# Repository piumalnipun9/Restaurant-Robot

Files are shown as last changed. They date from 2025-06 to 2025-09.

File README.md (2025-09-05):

# 🤖 Evora: The Restaurant Service Robot

Evora is a modular, intelligent restaurant robot designed to enhance customer service by autonomously navigating dining areas, delivering food, interacting with guests, and providing real-time feedback. Inspired by commercial systems like BellaBot, Evora integrates mobility, interactive communication, and advanced control systems into a robust, compact design.

---

## 📦 Project Overview

Evora combines a SAM3X8E microcontroller-powered brain with reliable sensor arrays, display and audio feedback systems, and a solid mechanical frame. The subsystems are interconnected via a full-duplex RS-485 communication bus for high-speed, noise-immune data exchange.

---

## 🚀 Key Features

### 🧠 Intelligent Navigation
- **Sensors**: Equipped with **OMRON E2E inductive proximity sensors** and **A02 object avoidance modules**.
- **Capabilities**: Autonomous routing, dynamic obstacle avoidance, and safe maneuvering in busy dining environments.

### 📺 Interactive Display System
- **Display**: 7.0” TFT LCD with SSD1963 controller.
- **Function**: Displays digital menus, navigation instructions, and order confirmations.

### 🔊 Voice Feedback
- **Audio Chain**: MAX98357A DAC → Winbond W25Q128JV flash → AS041008C speaker.
- **Purpose**: Provides voice prompts and responses for improved user interaction.

### 🍽️ Tray Delivery Mechanism
- **Design**: Multi-tray system, each tray supports up to **10 kg**.
- **Engineering**: Balance and safety optimized; FEA confirms up to **265 N** load with **SF = 2**.

### 🛜 RS-232 Communication Bus
- **Architecture**: Full-duplex, multi-node capable.
- **Benefits**: Real-time communication, high noise immunity, scalable subsystem integration.

### 🔋 Power System
- **Battery**: Replaceable power unit supports **12–24 hours** operation.
- **Recharge Time**: ~4.5 hours for full cycle.

### 🛡️ Safety & Hygiene
- Emergency stop button.
- Collision detection.
- Food-safe materials and build quality.

### 🧱 Modular and Scalable
- Subsystems are modular for **easy upgrades**, **repair**, and **customization**.
- Adaptable to various restaurant layouts and service models.

---

## 🖼️ Robot Preview

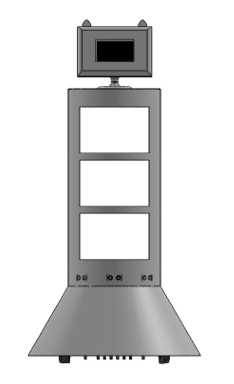
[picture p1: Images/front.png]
Front View of Evora

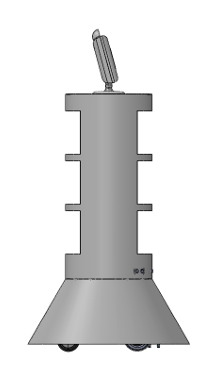
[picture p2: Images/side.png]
Side View of Evora

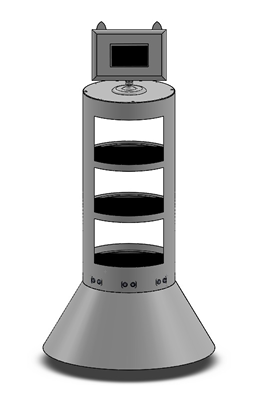
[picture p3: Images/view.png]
View1 View of Evora

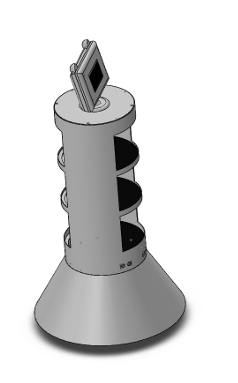
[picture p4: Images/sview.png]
View2 View of Evora


## 🖼️ Working Product
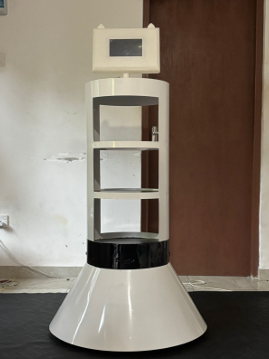
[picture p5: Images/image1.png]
  

## 🧩 PCB Design

The system is implemented on a compact 4-layer PCB to support noise-sensitive signals and high-current paths. The design emphasizes power and signal integrity while keeping the layout compact for integration into the robot chassis.

- *Top & Bottom Layers*: Signal routing  
- *Inner Layers*: Dedicated Ground and Power planes  
- *Key Considerations*:
  - Wide polygon pours for power
  - Matched-length routing for differential pairs
  - Test points for debugging and maintenance
  - Modular breakouts for sensors and displays

---

## 🖼 PCB Visuals

| Layer Stackup | 3D PCB View | 2D PCB Layout |
|---|---|---|
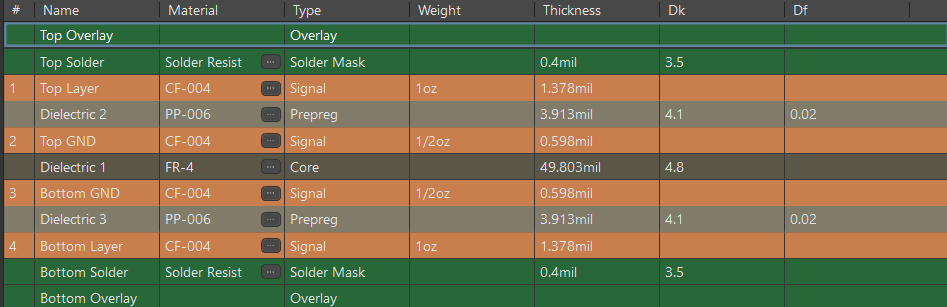
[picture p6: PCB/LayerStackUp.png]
Layer Stackup
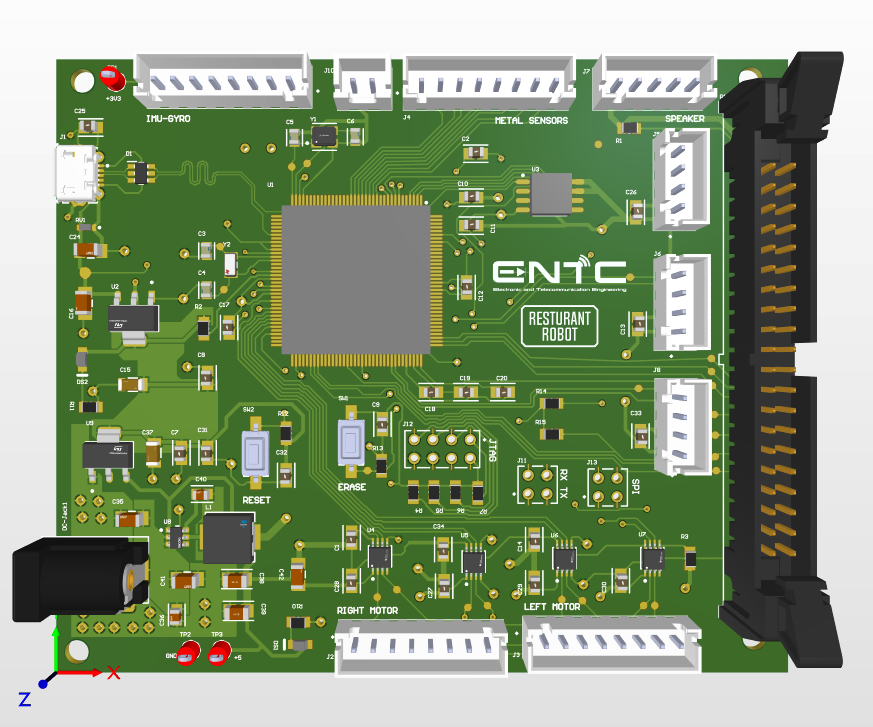
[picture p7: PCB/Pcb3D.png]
3D PCB
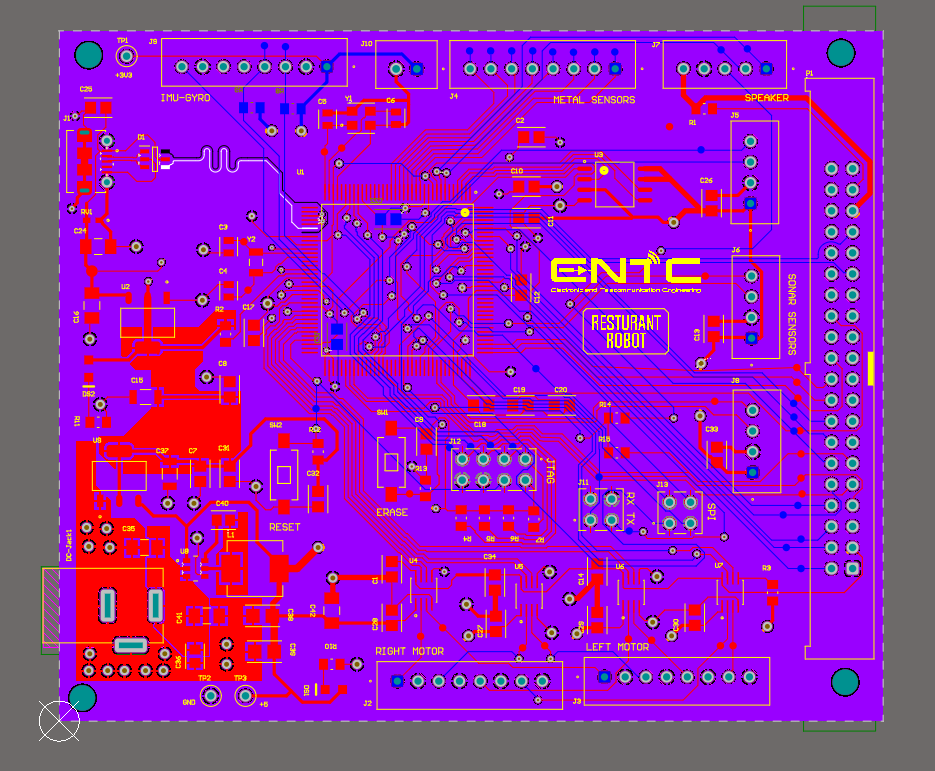
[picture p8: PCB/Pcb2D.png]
2D PCB
|  |  |  |

> 📝 The PCB height and layout were optimized to accommodate onboard regulators, high-power traces, and external motor drivers.

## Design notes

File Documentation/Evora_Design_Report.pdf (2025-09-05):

University of Moratuwa

Faculty of Engineering

Department of Electronic & Telecommunication Engineering

EN2160 - Electronic Design Realization

# Restaurant Robot

# Design Report

### Team Members:

1. Arachchi M.B.F 220040T
2. Bandara I.W.T.N 220061H
3. Boralugoda M.S 220074B
4. Karunathilake K.D.K 220310X
5. Peiris P.I.U 220452H
6. Sanjeewa P.M.G.P.N 220577U
7. Senaweera S.A.H.D 220596C
8. Viduranga J.K.A 220663F
9. Wijayarathna K.K.B.C 220705M
10. Wijenayaka M.B.T.I 220711D

July 11, 2025

Restaurant Robot | Design Report

## Contents

1 Introduction | 4
2 System Overview | 4
3 Review of Reference Product | 6
4 Block diagram | 9
5 Mechanical Design | 12
6 Hardware Design | 17

7 New Design Iteration | 32
8 Updated Mechanical Design | 32
9 Assembled Robot | 33
10 Related Calculations | 33
11 Power Supply Design | 35
12 PCB Design | 35
13 Firmware Development | 38
14 RS-232 Communication Integration | 39
15 Final Design Iteration - Overview | 40
16 Block Diagram | 40

17 Power Supply | 40
18 Display | 41
19 Enclosure Design | 42
20 PCB | 45
21 PCB Pin Allocation | 46
22 Acceleration Curve | 49
23 Firmware | 50
24 Conclusion | 50
A Appendices | 52

## 1 Introduction

### 1.1 Background of the project

Due to swift progress in service robotics and the growing need for automation in the hospitality sector, restaurant service robots have surfaced as a successful way to improve operational efficiency and increase customer experience.The worldwide shift towards contactless services, particularly during the pandemic, has expedited the incorporation of robots in customer-oriented settings.Reference models such as the BellaBot have illus-trated the viability of these robots in traversing challenging situations and executing delivery missions with considerable reliability.
Our project aims to create a restaurant robot specifically designed for indoor settings, like caf´es and dining halls. It is engineered to autonomously deliver food and engage with consumers, thereby lessening the burden on human personnel and reducing service inaccuracies.This robot provides a practical and scalable solution for the future of smart eating experiences through the integration of efficient mechanical design, robust control systems, and user-centered interaction elements.

## 2 System Overview

### 2.1 Description

Drawing inspiration from existing commercial solutions like BellaBot, this system in-tegrates mobility, interactive communication, and intelligent control within a compact, modular design.The robot is powered by the SAM3X8E microcontroller, which offers the necessary computational capabilities for controlling motors, processing sensor data, and managing display and communication tasks. The entire system is structured around multiple interconnected subsystems that communicate via a robust RS-485 full-duplex bus, allowing synchronized and reliable data exchange between modules.

### 2.2 User Need Analysis

### 2.2.1 User Needs and Expectations

1. Efficient and Accurate Food Delivery - Customers expect robots to deliver food quickly and accurately to the correct table.
2. User-Friendly Interaction - Robots should have an easy-to-use interface for customers and restaurant staff.

3. Navigation and Obstacle Avoidance - Robots must safely navigate through a crowded restaurant while avoiding obstacles.
4. Food Pickup Automation - Kitchen staff require the robot to stop at a desig-nated area to load orders.
5. Hygiene and Safety Compliance - Ensuring proper sanitization measures and food safety standards.
6. Order Status Updates - Customers may want real-time updates on their orders via displays or audio prompts.

### 2.2.2 Stake Holder Mapping

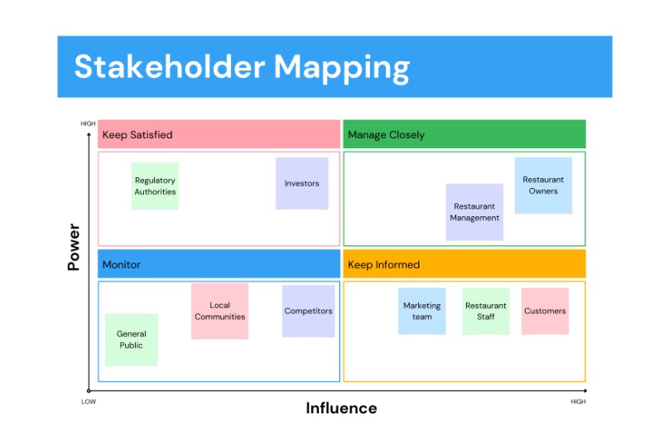
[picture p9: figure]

Figure 1: Stakeholder Map

### 2.3 Key Features in our Robot:

- Autonomous Navigation: The robot is equipped with inductive proximity sen-

sors (OMRON E2E) and object avoidance modules (A02 series), allowing it to nav-

igate safely and efficiently through dynamic environments such as crowded dining areas.

- Interactive Display System: A 7.0” TFT LCD with SSD1963 controller is used

to display menus, guide customers, and confirm orders, ensuring a user-friendly interface.

- Voice Feedback Capability: The robot uses a speaker system powered by the

MAX98357A DAC, Winbond W25Q128JV flash memory, and AS041008C speaker to provide audio feedback, improving human-robot interaction and approachability.

- Tray Delivery Mechanism: The robot supports multiple trays, each capable of

holding up to 10 kg. The mechanical design focuses on balance and safety during motion.

- Robust Communication Bus: Half-duplex RS-232 communication is used be-

tween distributed modules, ensuring real time data transmission with high noise immunity and support for multiple nodes.

- Efficient Power System: A replaceable battery provides 12–24 hours of operation

per charge, with a recharge time of approximately 4.5 hours, allowing for extended service during peak hours.

- Structural Reliability: Finite Element Analysis (FEA) using SolidWorks con-

firmed the design of the tray can handle forces up to 265 N with a safety factor of 2, ensuring mechanical robustness under load.

- Safety Features: The robot includes emergency stop functionality, collision de-

tection, and is built with hygiene compliant materials suitable for food service environments.

- Modular and Scalable Architecture: The robot’s design allows for future ex-

pansions and upgrades. Each subsystem is modular making maintenance easier and improving adaptability to different restaurant layouts or requirements.

## 3 Review of Reference Product

The design and functionality of the restaurant robot were inspired by BellaBot, a commercial service robot developed by Pudu Robotics. BellaBot is widely used in the hospitality industry for efficient and contactless food delivery.

Figure 2: Bella bot by Pudu Robotics

### Specifications

- Manufacturer: Pudu Robotics
- Height: 1290 mm
- Width: 565 mm
- Depth: 537 mm
- Weight: Approximately 55 kg
- Load Capacity: Up to 40 kg (10 kg per tray, with 4 trays)
- Battery Type: Lithium-ion
- Battery Life: 12–24 hours on a full charge

- Charging Time: Approximately 4.5 hours
- Navigation: Laser SLAM + Visual SLAM dual system
- Touch Interface: 10.1” touchscreen display
- Obstacle Avoidance: Multi-sensor fusion for 360° environmental perception
- Interactive Features: LED cat-like facial expressions, voice prompts, ambient

lighting effects

- Speed: Adjustable, up to approximately 1.2 m/s

### Key Functionalities

- Autonomous navigation with multi-point delivery
- Multi-modal interaction (touchscreen, voice, LED facial expressions)
- Automatic return to charging dock
- Obstacle avoidance in dynamic environments

Note: The BellaBot served as the reference model during conceptualisation and design requirement analysis for this project to ensure practical feature selection, ergonomic considerations, and user experience alignment. While BellaBot uses Laser SLAM and Visual SLAM for navigation, our product adopts a metal line following method, which is more suitable and cost-effective for local restaurant settings.

## 4 Block diagram

### 4.1 Conceptual Design Stage

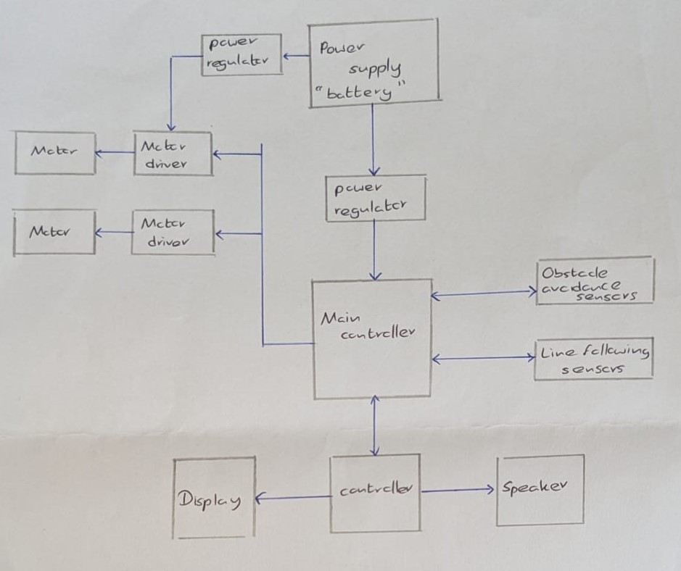
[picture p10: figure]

### 4.2 Evaluation

### 4.3 Final block diagram

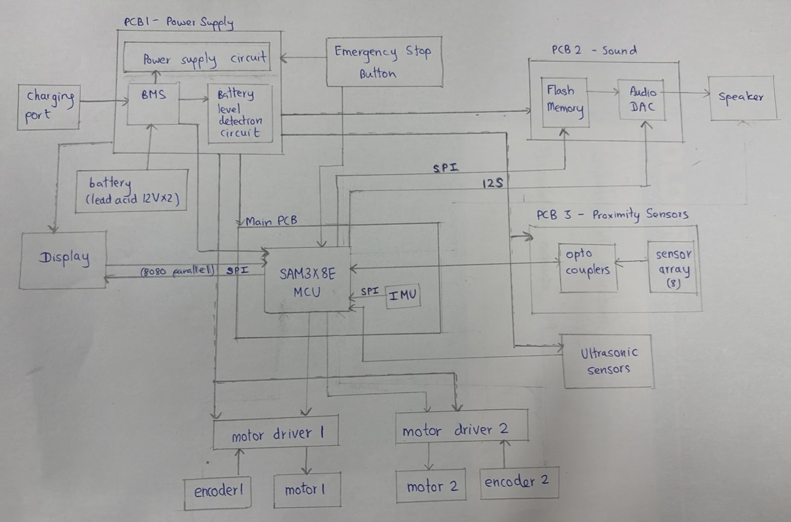
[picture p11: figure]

## 5 Mechanical Design

### 5.1 Conceptual Design Stage

### 5.1.1 Evaluation

### 5.2 Final Cross Pollinated Design

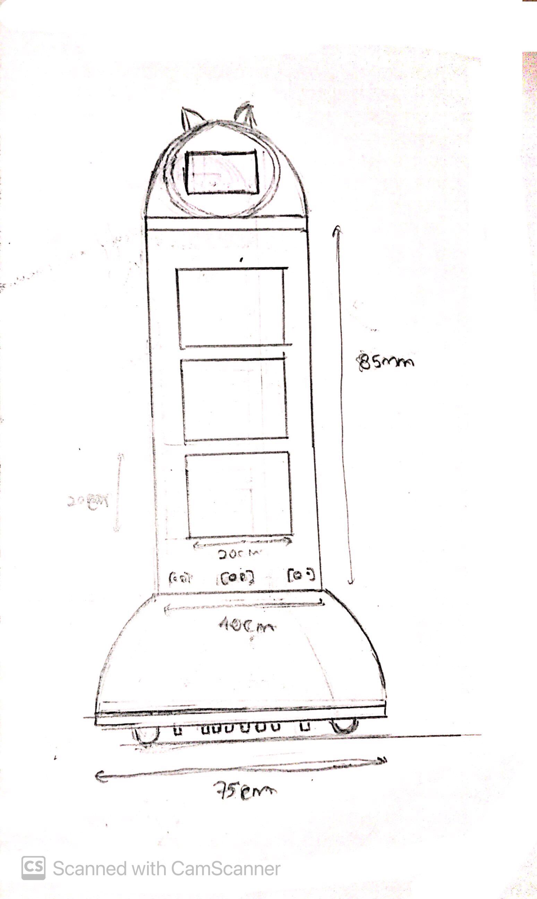
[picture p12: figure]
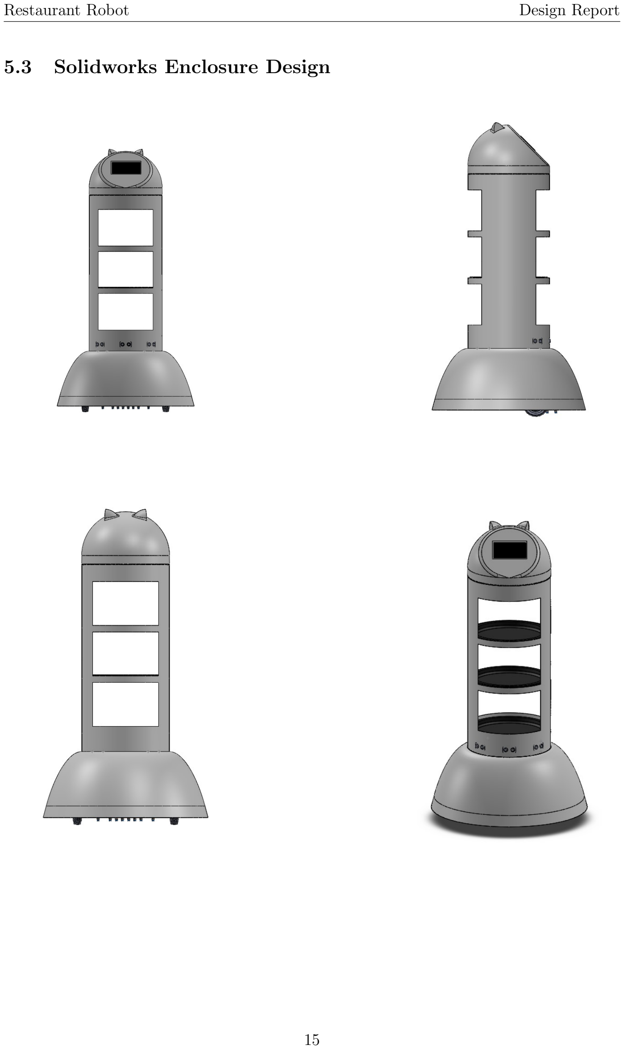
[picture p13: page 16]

### 5.3 Solidworks Enclosure Design

Figure 3: Frame designed using steel

Figure 4: Plate designed using plastic

### 5.4 Analysis

Tray Weight Analysis and Stress Simulation

## 6 Hardware Design

### 6.1 Sensors

### 6.1.1 Metal Detecting Sensors

1. OMRON welding proximity sensors( E2EW Series )
2. OMRON welding proximity sensors( E2E/E2EQ Next Series)
3. IMB Inductive proximity Sensor
4. Balluf Inductive Proximity Sensors

Table 1: Comparison
Feature | OMRON E2EW | OMRON E2E/E2EQ | SICK IMB | Balluff BES004E
Sensitivity | 3 | 3 | 2 | 3
Detection Range | 2 | 3 | 3 | 3
Response Time | 2 | 3 | 3 | 3
Robustness | 3 | 2 | 3 | 3
Harsh Environment Suitability | 3 | 2 | 3 | 3
Mounting Flexibility | 2 | 3 | 3 | 3
Interface Options | 2 | 3 | 2 | 2
Ease of Integration | 2 | 3 | 2 | 2
Availability | 3 | 3 | 2 | 3
Price Efficiency | 2 | 3 | 2 | 2
Total Points | 24 | 28 | 25 | 27

After carefully considering all the options available, we have chosen the OMRON welding proximity sensors( E2E/E2EQ Next Series) for our project.

### 6.1.2 Obstacle Detecting sensors

1. A02 series sensor module

Table 2: A02 series sensor module
Features | Advantages | Applications
3cm small blind zone | Small blind zone (5cm) | Horizontal distance sensing
3.3–5V power input | Water and dust resistivity | Car parking system
Closed waterproof bistatic probe | Strong anti-interference ability | Robot avoidance and auto-matic control

2. ME007YS Series Sensor Module

Table 3: ME007YS Sensor Module
Features | Advantages | Applications
Intelligent signal process-ing circuit, small blind zone | High-accuracy distance sens-ing | Horizontal distance sensing
Multiple interfaces: PWM, UART Auto, UART Ctrl, Switch | Stable temperature-compensated sensing | Solid level monitoring
3. A13 Series Sensor Module

Table 4: A13 Series Sensor Module
Features | Advantages | Applications
Reflective structure with narrow beam angle | High sensitivity and stable de-tection | Horizontal distance sensing
Multiple output modes: UART, PWM, RS485, Switch | Internal temperature compen-sation with anti-static design | Object classification and prox-imity sensing

Table 5: Ultrasonic Sensor Comparison
Feature | A02 Series | ME007YS Series | A13 Series
Blind Zone | 3 | 1 | 2
Measuring Range | 3 | 2 | 1
Water resistance | 3 | 2 | 0
Dust resistance | 3 | 2 | 0
Beam Angle | 3 | 3 | 1
Static Power Consumption | 3 | 2 | 2
Operating Current | 3 | 3 | 3
Temperature Range | 3 | 3 | 3
Accuracy | 3 | 3 | 3
Response Time | 3 | 2 | 2
Interface Variety | 2 | 3 | 3
Form Factor / Size | 3 | 2 | 2
Stability | 3 | 2 | 3
Anti-Static Design | 2 | 3 | 3
Temperature Compensation | 2 | 3 | 3
Total Points | 42 | 36 | 31

After carefully considering all the options available, we have chosen the A02 Series sensor for our project.

### 6.2 Actuators

### 6.2.1 Motors

1. Calculations
(a) Robot Requirements
- Total robot mass: 45 kg
- Drive system: 2 direct-drive wheels (differential configuration)
- Maximum speed: 0.5 m/s
- Acceleration: 0.2 m/s²
- Wheel diameter: 127 mm (5 in)
- Indoor use only: Low noise, non-marking tread required
(b) Motor Torque Calculation
- Force per Wheel :

F =

45 · 0.2
2

= 4.5 N

- Rolling Friction per Wheel: For rubber wheels on carpet,the rolling

resistance coefficient(Crr) is assumed to be in the range 0.03–0.05.For this

calculation,we use an estimated value of Crr=0.05.

Fr =

Crr · m · g
n

=

0.05 · 45 · 9.81
2

=

22.0725
2

= 11.036 N

- Torque Requirement :

τ = F · r = (4.5 + 11.04) · 0.0635 = 0.98679 N · m

Apply 2× safety margin:

τrequired ≈ 1.9736 N · m

- Required RPM:
Circumference = 2πr = 0.399 m | ⇒ | RPM = 0.5
| | 0.399
- 60 ≈ 75 RPM
2. Comparison

Table 6: Motor Comparison

Motor | Torque | Control | Efficiency | Cost | Integration | Feedback | Total
Pololu 37D Cytron SPG50 NEMA 23 (Open) NEMA 34 (Open) NEMA 23 Closed-Loop JMC Servo-Stepper | 15 14 22 25 24 25 | 10 10 15 15 20 19 | 10 10 9 8 13 12 | 12 14 12 10 13 10 | 14 14 13 10 14 12 | 0 0 0 0 10 10 | 61 62 71 68 94 88

After carefully considering all the options available, we have chosen the NEMA 23 Closed Loop Stepper Motor for our project.We decided to purchase YS Series 1 Axis Closed Loop Stepper CNC Kit from stepper online which includes a S Series Nema 23 Closed Loop Stepper Motor and a CL57Y Y Series Closed Loop Stepper Driver.

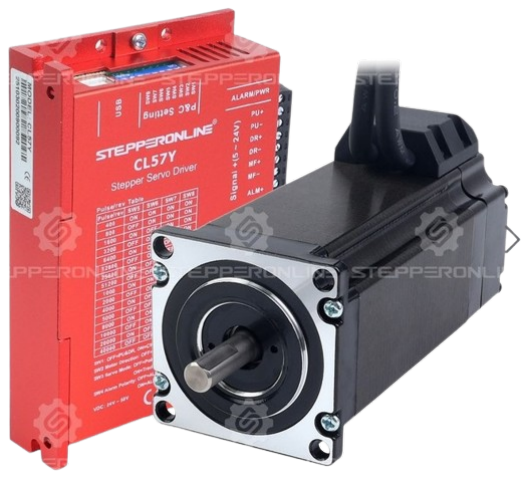
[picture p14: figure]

3. Motor Specifications
- Manufacturer Part Number: 23HS40-5004D-E1K-1M5
- Motor Type: Bipolar Stepper
- Step Angle: 1.8°

- Holding Torque: 3.00 Nm (424.83 oz.in)
- Rated Current per Phase: 5.0 A
- Phase Resistance: 0.7 Ω ± 10%
- Inductance: 2.3 mH ± 20% (1 kHz)
- Insulation Class: B (130°C / 266°F)
- Frame Size: 57 × 57 mm
- Body Length: 122 mm
- Shaft Diameter: 8 mm
- Shaft Length: 22 mm
- D-Cut Length: 15 mm
- Cable Length: 1500 mm
4. Encoder Specifications
- Output Circuit Type: Differential type
- Encoder Type: Optical Incremental
- Encoder Resolution: 1000 PPR (4000 CPR)
- Output Signal Channels: 2 channels
- Supply Voltage Range: 4 V – 5 V
- Output Current: 100 mA
- Output High Voltage: 5 V
- Output Low Voltage: 4.5 V
- Maximum Output Frequency: 60 kHz
5. Driver Specifications
- Output Peak Current: 0–7 A (0–5 A RMS)
- Input Voltage: +24–50 VDC (Typical: 36 VDC)
- Logic Signal Current: 7–16 mA (Typical: 10 mA)
- Pulse Input Frequency: 0–200 kHz
- Pulse Width: 2.5 µs
- Isolation Resistance: 500 MΩ

### 6.3 Display and UI

The restaurant robot project aims to enhance customer experience by automating tasks such as taking orders, displaying menus, and providing real-time updates. A display module is critical for this purpose, serving as the primary interface for user interaction and information sharing and we will be using a 7.0” TFT LCD Module with SSD1963 Controller for our application.

### 6.3.1 Display Specifications

Parameter | Specification
Model | 7.0” TFT LCD Module
Resolution | 800×480 pixels
LCD Type | TFT Transmissive Normal White
Interface | 16-bit parallel bus interface
PCB Color | Blue
Backlight Power Supply | On-board 400 mA DC-DC Boost regulator
Module Dimensions | 186 mm × 106 mm × 23 mm
Active Area | 154 mm × 86 mm
Pixel Pitch | 0.179 mm × 0.179 mm
Pin Header | Standard 2×20 2.54 mm pin header
Weight | 410 grams

### 6.3.2 Electrical Specifications

Parameter | Specification
Driver Chip | SSD1963
Data Port Voltage | IOVCC = VCC = 2.8V 3.3V
Operating Temperature | -20°C to +70°C
Storage Temperature | -30°C to +80°C
Touch Type | Resistive touch
Connection Method | 2.54mm pin header

### 6.3.3 Advantages

- High resolution (800×480 pixels) ensures crisp visuals.
- Resistive touch screen enables user interaction.
- Integrated backlight regulator simplifies power management.
- Pre-tested initialization code saves development time.
- Wide compatibility with the STM32 microcontroller.

### 6.4 Sound Module

The sound system in the restaurant robot is designed to provide a high-quality audio output for user interactions. The following components are selected for optimal performance.

### 6.4.1 Required Components

1. I2S to Analog Converter Options
- PCM5102A : The PCM5102A is used as the I2S DAC to convert digital

signals from the MCU into high-fidelity analog audio output. It supports up to 32-bit, 384 kHz audio and has a built-in low-noise voltage regulator for stable operation.

- MAX98357A (I2S DAC + Amplifier) The MAX98357A is an integrated

solution that combines an I2S DAC with a Class-D amplifier, providing both digital-to-analog conversion and speaker driving capabilities in a single pack-age. This space-efficient solution simplifies the audio signal chain by eliminating the need for a separate amplifier IC.Key features of this are :

– Integrated I2S audio DAC and Class-D amplifier

– 3.2W output into 4Ω speaker at 5V

– No external components required for filtering

– Low quiescent power consumption

– Filterless modulation scheme

2. Speaker Driver IC Options
- PAM8403 : The PAM8403 Class-D amplifier is a smaller, lower power option

suitable for applications where space and power consumption are critical. It provides up to 3W per channel and is easy to implement.

- LM386 : The LM386 is a classic low-voltage audio power amplifier that can

drive speakers directly. It offers adjustable gain and volume control capabilities through simple external components.Some of the key features are

– Operating voltage: 4V–12V

– Output power: 0.25W to 1W (depending on supply voltage and load)

– Adjustable gain from 20 to 200

– Low quiescent current drain

– Hardware volume control capability via external potentiometer

– Simple implementation with minimal external components

3. Flash Memory : For storing pre-recorded audio files, the W25Q256 (32MB) or W25Q128 (16MB) NOR Flash memory is used. It communicates with the MCU

via SPI and ensures fast, non-volatile storage for voice prompts and sound effects.

4. Speaker Options
- AS07108PO-LW152-WR-R (PUI Audio) :A compact yet powerful speaker is required to match the amplifier’s output. A 3W-5W, 8Ω full-range speaker

is chosen to deliver clear voice playback with a sensitivity of 86dBA.

- Visaton K 50 SQ (4ohms, 2W)

– Power handling: 2W RMS

– Impedance: 4 ohms

– Sensitivity: 84 dB (1W/1m)

– Type: Square dynamic speaker, paper cone

### 6.4.2 Design Considerations

1. Option 1: PCM5102A + PAM8403
- Highest audio quality
- Digital volume control via STM32
- Higher component count
- More PCB space required
2. Option 2: PCM5102A + LM386
- Good audio quality
- Hardware volume adjustment possible
- More analog components required
- Lower power output (0.25W–1W)
3. Option 3: MAX98357A only
- Simplest implementation
- Smallest PCB footprint
- Digital volume control only
- Good power output (3.2W at 5V)

MAX98357A provides the simplest implementation by integrating both the amplifier and digital volume control in a single chip, eliminating the need for additional analog components and reducing system complexity. Its small footprint makes it ideal for designs with tight space constraints.Despite its compact size, the MAX98357A delivers 3.2W of power output at 5V, which is sufficient for many audio applications, offering efficient amplification without the need for a separate power amplifier.

### 6.5 Microcontroller

### 6.5.1 Evaluation

After carefully considering all the options available, we have chosen the SAM3X8E microcontroller for our project.

Table 7: Microcontroller Comparison

Feature | MX RT1064 | PIC32MZ | SAME70 | SAM3X8E | Teensy 3.5/3.6 | ATSAM4S | ATSAM3S
Core | 3 | 2 | 3 | 2 | 3 | 3 | 2
I/O Pins | 3 | 3 | 2 | 2 | 3 | 2 | 1
Memory | 3 | 3 | 2 | 1 | 3 | 2 | 2
Speed | 3 | 3 | 2 | 1 | 3 | 2 | 2
USB Support | 3 | 3 | 2 | 2 | 3 | 2 | 2
Communication | 3 | 3 | 3 | 2 | 3 | 3 | 2
Motor Control | 3 | 2 | 2 | 2 | 3 | 3 | 2
DMA Support | 3 | 2 | 3 | 0 | 2 | 2 | 2
Power Efficiency | 2 | 2 | 2 | 3 | 2 | 3 | 3
Touch Interface | 3 | 3 | 3 | 2 | 2 | 2 | 1
Parallel Interface | 3 | 2 | 2 | 3 | 1 | 2 | 1
Development Tools | 3 | 2 | 2 | 3 | 3 | 3 | 2
Community Support | 1 | 2 | 3 | 2 | 3 | 2 | 2
Cost Efficiency | 0 | 1 | 1 | 3 | 0 | 2 | 3
Ease of Programming and Debugging | 2 | 2 | 2 | 2 | 3 | 2 | 2
Low Power Modes | 2 | 1 | 2 | 2 | 2 | 3 | 3
Total Points | 41 | 38 | 41 | 42 | 40 | 42 | 39

### 6.5.2 Details of SAM3X8E

1. Core and Speed : We chose the SAM3X8E because it features an ARM Cortex-M3 core running at 84 MHz. Although there are faster options available, this clock speed provides the perfect balance between performance and power consumption for our requirements. The SAM3X8E is powerful enough to handle tasks like driving the SSD1963 LCD, managing motor control, and processing sensor data, without being overkill for our project.
2. I/O Pins : We need a microcontroller with sufficient digital and analog I/O pins

to handle the requirements of the display,motor controller, sensor inputs, and sound module. The SAM3X8E offers 54 digital I/O pins and 12 analog pins, which is more

than enough to support

- SSD1963 : The parallel interface (16-bit) is fully supported with available

digital pins

- Motor Control: We can easily control multiple motors using PWM signals.
- Sensor Inputs: The 12 analog pins give us ample capacity to handle sensor

data.

- Sound Module: We have enough I/O pins to interface with the sound mod-

ule.

3. Communication Interfaces : For communication, we need a microcontroller that supports protocols like SPI, I2C, and UART. The SAM3X8E supports all these protocols, which gives us the flexibility to interface with the SSD1963 LCD, motor controllers,sensors, and sound modules. The microcontroller’s ability to handle these interfaces makes it ideal for our design.
4. Development Tools : We also considered the availability of development tools, and the SAM3X8E comes with support for Atmel Studio, which is a free and powerful tool for development. It’s a great advantage to be able to use a professional IDE without any additional costs.
5. Parallel Interface (16-bit/8-bit) : A key feature for us was the support for a

16-bit parallel interface. This is critical for driving the SSD1963 display, as parallel communication allows for faster data transfer compared to serial interfaces. The SAM3X8E provides this interface, ensuring that we can update the display quickly and efficiently.

6. Cost : We also found that the SAM3X8E is reasonably priced compared to other microcontrollers with similar features. It offers a good balance between performance and cost, making it an affordable option for our project.

### 6.5.3 Power Requirements Analysis

The table below shows the power consumption of all robot components:

Component | Quantity Voltage (V) Current (A) Power (W)
Nema 23 motors | 2 | 24 | 4.2 | 201.6
AO2 PWM Ultrasonic sensors | 3 | 5 | 0.04 | 0.6
Proximity sensors | 8 | 12 | 0.003 | 0.288
7-inch TFT LCD Display | 1 | 5 | 0.12 | 0.6
SAM3X8E MCU | 1 | 3.3 | 0.8 | 2.64
Motor drivers CL57T (logic) | 2 | 24 | 0.016 | 0.768
Display backlight (21 LED) | 1 | 12 | 0.14 | 1.68
Total Power Consumption | | | | ≈ 210

### 6.5.4 Battery Capacity Calculation

Short-Duration Operation (2 hours)

- Energy requirement: 210 W × 2 h = 420 Wh
- Capacity at 24V: 420 Wh
24 V = 17.5 Ah
- Recommended capacity (with 20% safety margin): 17.5 Ah × 1.2 = 21 Ah

Extended Operation (4 hours)

- Energy requirement: 210 W × 4 h = 840 Wh
- Capacity at 24V: 840 Wh
24 V = 35 Ah
- Recommended capacity (with 20% safety margin): 35 Ah × 1.2 = 42 Ah

For testing purposes and considering affordability, we will use 9Ah batteries in the current prototype.

### 6.6 Wheels

### 6.6.1 Wheel Options

1. BaneBots Wheel
2. Tebru Industrial Robot Wheel
3. AGV Drive Wheel
4. Modified Heavy Duty Wheel - Robokits India

### 6.6.2 Shaft Hub Options

1. Pololu 8mm Hub

In conclusion, finding the right wheel for our 8 mm shaft setup has proven challenging due to either compatibility issues or high costs. The best solution appears to be going for a less costly wheel, because of that we chose the Modified Heavy Duty Wheel from Robokits India.

### 6.7 Flow Chart

### 6.7.1 Conceptual Design

### 6.7.2 Evaluation

### 6.7.3 Final Cross-Pollinated flow chart

## 7 New Design Iteration

This section outlines the key improvements and additions made in the latest iteration of the design. Each update was implemented based on evolving project requirements.

## 8 Updated Mechanical Design

In the latest iteration, the SolidWorks enclosure design was revised to improve manufac-turability and cost effectiveness.

### 8.1 Updated SolidWorks Design

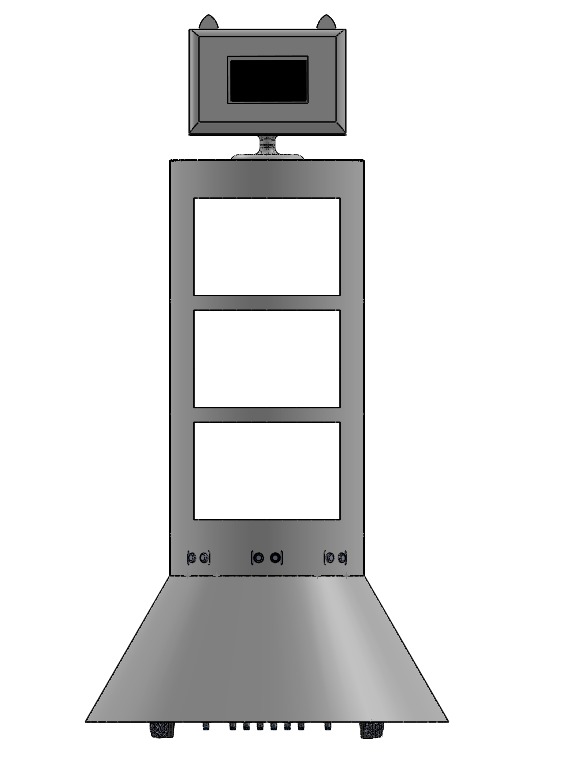
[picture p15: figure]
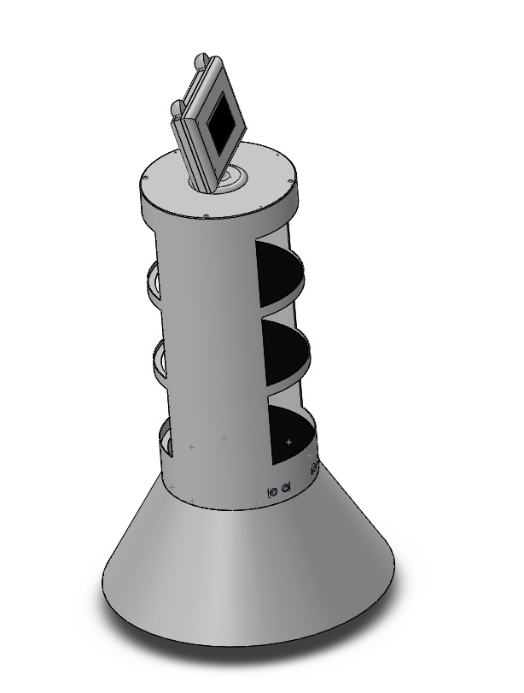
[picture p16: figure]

## 9 Assembled Robot

Figure 5: Robot After Assembly

## 10 Related Calculations

### 10.1 Mathematical Equation for Acceleration S-Curve

The acceleration velocity profile of the robot is modeled using a sigmoid function. This approach enables smooth transitions from rest to the maximum velocity Vmax, avoiding abrupt acceleration spikes that could affect mechanical stability or user comfort. The velocity function v(t) over time is defined as:

v(t) = Vmax 1 + e −K(t−X0)

Where:

- v(t) — velocity at time t
- Vmax — maximum velocity (e.g., 50.0)
- K — steepness factor that controls how fast acceleration ramps up (positive con-

stant)

- X0 — midpoint of the sigmoid curve (i.e., the time when velocity reaches Vmax
2

)

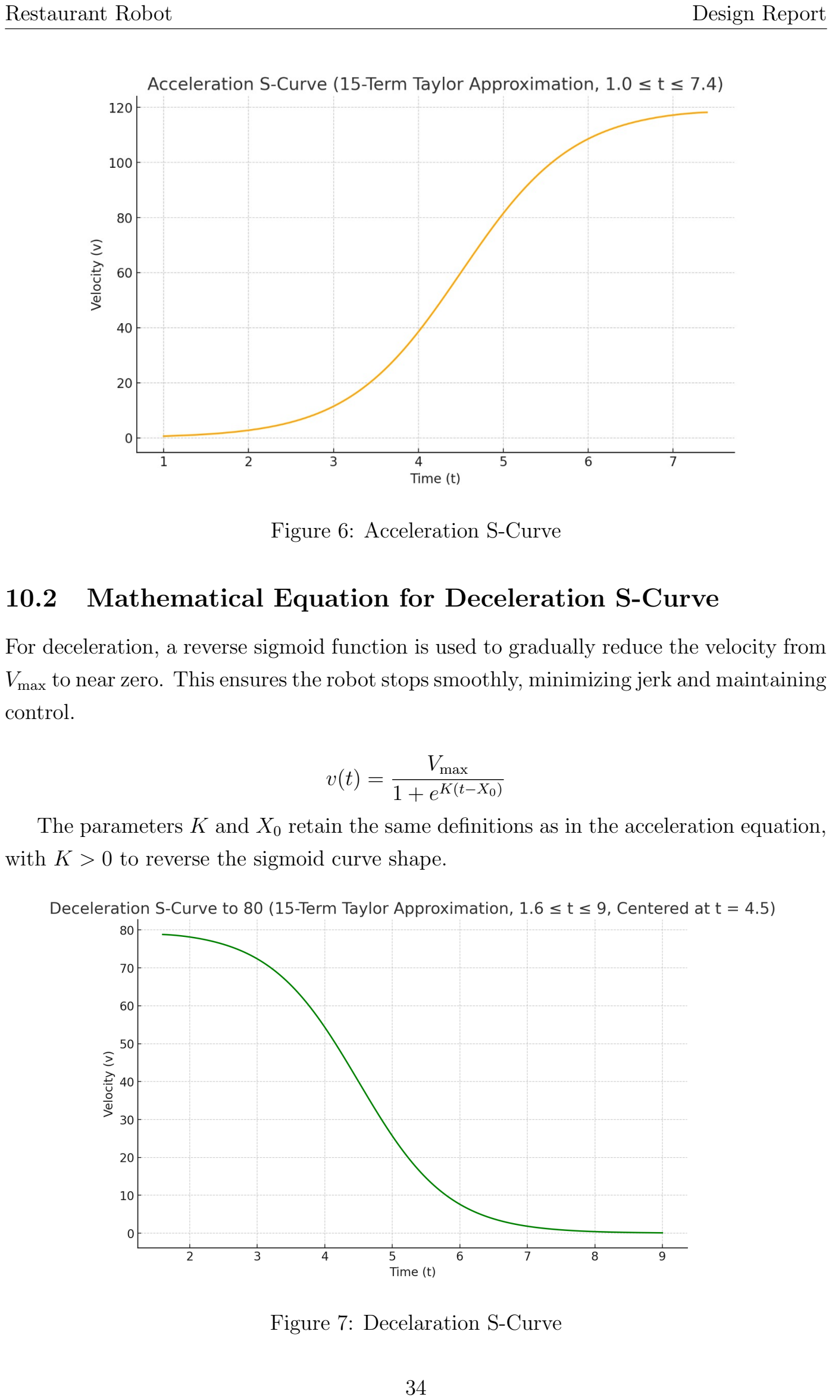
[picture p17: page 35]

Figure 6: Acceleration S-Curve

### 10.2 Mathematical Equation for Deceleration S-Curve

For deceleration, a reverse sigmoid function is used to gradually reduce the velocity from Vmax to near zero. This ensures the robot stops smoothly, minimizing jerk and maintaining control.

v(t) = Vmax 1 + eK(t−X0)

The parameters K and X0 retain the same definitions as in the acceleration equation, with K > 0 to reverse the sigmoid curve shape.

Figure 7: Decelaration S-Curve

### 10.3 Use in Motion Planning

These equations were used to program smooth acceleration and deceleration phases in the robot’s motor control logic. By adjusting the parameters K and X0, the team could fine-tune how quickly or gradually the robot transitions between different speeds, enabling efficient, safe, and comfortable movement across the restaurant floor.

## 11 Power Supply Design

The power supply system was designed to provide stable and efficient voltage levels required by various subsystems of the project. A rechargable LiPo battery pack was selected as the primary power source due to its high energy density, lightweight nature, and ability to deliver high discharge currents suitable for motor drivers and processing units.

### 11.1 Power Regulation Architecture

The output from the LiPo battery is first boosted to 24V using a high-efficiency DC-DC boost converter. This 24V rail serves as the main power bus for high-power components such as motor drivers. Subsequently, the 24V line is stepped down to 12V using a buck converter to power intermediate subsystems.
Within the main PCB, the 12V supply is further regulated to 5V and 3.3V using linear and switching regulators to supply logic-level components, sensors, and microcontrollers. This tiered voltage regulation strategy ensures optimal power distribution, minimizes power losses, and isolates noise-sensitive components from high-current lines.

## 12 PCB Design

### 12.1 Main PCB Design

A 4-layer PCB was designed to meet the signal integrity, power distribution, and compact layout requirements of the system. This multi-layer structure allows for better separation of power and signal planes, reduced electromagnetic interference, and efficient routing.

### 12.2 Layer Stackup

The printed circuit board (PCB) for the robot was designed as a 4-layer stack to ensure signal integrity, reduce electromagnetic interference (EMI), and support high-current

power delivery. The layer configuration is as follows:

Table 8: PCB Layer Stackup
Layer | Description
Top Layer | Signal routing
Layer 2 | Ground plane
Layer 3 | Power plane and additional ground zones
Bottom Layer | Signal routing

Figure 8: Layer-wise PCB Views

### 12.3 Key Considerations

The following key considerations were taken into account during the PCB design and fabrication process:

- Wide Power Traces and Polygon Pours: Power traces were made wider and

polygon pours were applied to high-current paths to minimize voltage drop and thermal resistance, thereby improving overall power integrity and heat dissipation.

- Strategic Component Placement: Components were placed to ensure optimal

signal flow, minimize trace lengths, and reduce noise. Special attention was given to the placement of sensitive analog and high-frequency components.

- Voltage Regulator Placement: The voltage regulator was positioned in accor-

dance with the layout guidelines provided in its datasheet, ensuring proper thermal management and reliable voltage regulation.

- Differential Pair Routing: Differential signal lines were routed using matched-

length traces with controlled impedance. This reduces electromagnetic interference (EMI) and ensures signal integrity for high-speed communication.

- Test Point Provisioning: Dedicated test points were added at critical locations

across the board to facilitate debugging, signal probing, and quality control testing. This enhances the maintainability and testability of the final product.

### 12.4 PCB

Figure 9: Final PCB Renderings

### 12.5 Sensor Array PCB Design

In addition to the main control board, a separate PCB was designed specifically for the ultrasonic sensors. This modular approach allows for easier maintenance, signal isolation, and optimized sensor placement within the mechanical enclosure.

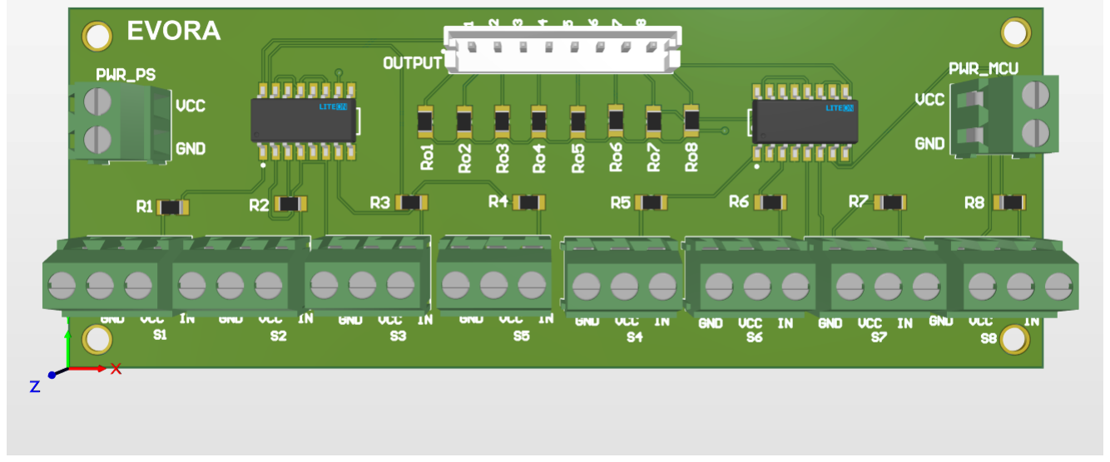
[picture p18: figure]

Figure 10: PCB for the Proximity Sensor array

## 13 Firmware Development

The firmware for the restaurant robot was developed in C using the Atmel Software Framework (ASF) and deployed on the SAM3X8E microcontroller. It manages key func-

tionalities such as line following, obstacle detection, motor control, display updates, and inter-module communication.

### 13.1 Modular Architecture

The firmware is divided into several functional modules, each responsible for a critical subsystem. These include:

- Motor Control: PWM signals are generated to drive two NEMA 23 closed-loop

stepper motors. Acceleration and deceleration are managed using S-curve velocity profiles for smooth motion.

- Sensor Handling: Data from proximity and ultrasonic sensors are continuously

read and processed to detect obstacles and junctions for decision-making during navigation.

- Line Following Algorithm: A PID control algorithm calculates error based on

sensor input and adjusts the motor speeds to follow metal paths embedded under the floor.

- S-Curve Velocity Profiling: Acceleration and deceleration curves are imple-

mented using sigmoid functions to ensure smooth speed transitions and mechanical stability.

- Display Interface: The 7” TFT LCD is controlled via a parallel interface to

display order status and user interaction elements. Display logic is separated from core navigation code for modularity.

- Obstacle Response: In case of detected obstacles, the robot executes a controlled

deceleration sequence and makes path decisions based on junction detection logic.

## 14 RS-232 Communication Integration

RS232 communication was integrated into the system to enable reliable serial communication between microcontrollers (MCUs), particularly for cases where asynchronous,

long-distance, or noise-tolerant data transmission is required. The MAX3232 transceiver module was used to convert TTL-level UART signals from the microcontroller to RS232-compliant voltage levels, allowing seamless interfacing with devices that operate on RS232 standards.
This module was chosen for its dual-channel support, low power consumption, and compatibility with a wide operating voltage range, making it ideal for embedded applications. A suitable DB9-compatible connector was included on the PCB for secure and standardized physical interfacing.
By incorporating RS232 communication, the design supports inter-MCU coordination, modular subsystem development, and future expandability with external debugging tools or legacy RS232-based controllers.

## 15 Final Design Iteration - Overview

This section presents the updates and changes implemented in the final design iteration of the restaurant robot. Throughout this stage, the team focused on refining critical subsystems to enhance the robot’s functionality and integration for deployment-ready performance. This final design iteration includes the replacement of the display module, redesign of the robot head, finalization of the power supply, and integration of custom PCBs into the robot to replace earlier development boards.

## 16 Block Diagram

This section presents the final block diagram of the restaurant robot, reflecting all system updates and integrations made in the final design iteration.

Figure 11: Final Block Diagram

## 17 Power Supply

In the final iteration, an updated power supply architecture was implemented to ensure stable operation of all subsystems. An 11.1V LiPo battery is used as the main power source. This voltage is boosted to 24V using a dedicated boost converter module, which supplies power to the two motor drivers and the ultrasonic sensor array. Additionally, the 11.1V battery voltage is bucked down to 9V using a buck converter module, and this 9V supply is provided to the main PCB. Within the PCB, onboard regulators are used to further regulate the voltage to 3.3V and 5V as required by the microcontroller, display module, and other electronic components.

Figure 12: Final Power Supply Block Diagram

## 18 Display

In the final design iteration, the initial 7-inch TFT LCD display was damaged due to an unexpected electrical issue that caused it to burn out. As a result, the team had to move on to a smaller display module due to budget constraints. The replacement display used was a TFT LCD Shield 2.4” Socket Touch Panel Module. Although smaller in size, this display provided adequate functionality for the robot’s interface requirements.
The touch display allows users to choose the table to be served and to turn on or off the googly eyes of the robot. Initially, the googly eyes were planned to be integrated graphically within the 7-inch display interface. However, due to the change in display size and resolution, the team implemented the googly eyes using two 8×8 LED matrices,

which effectively emulate two animated eyes on the robot’s head.

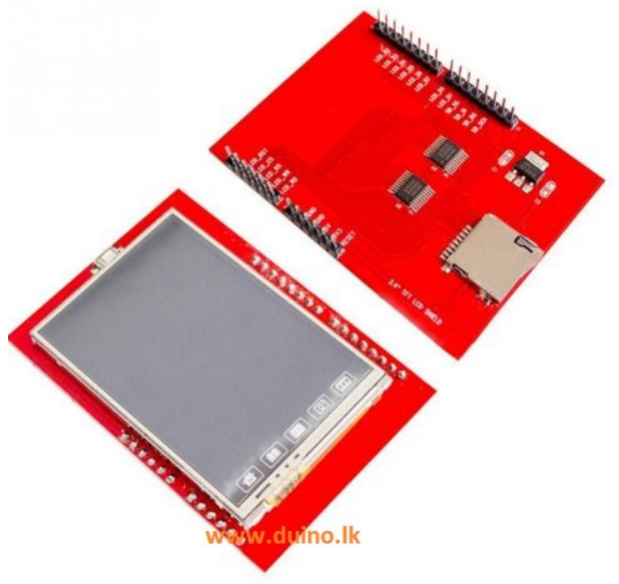
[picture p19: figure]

Figure 13: Touch Panel Module

Figure 14: LED Matrix

## 19 Enclosure Design

In the final design iteration, the enclosure design was updated only for the robot head to accommodate the change in display module. The head was redesigned to fit the smaller 2.4” TFT LCD touch display along with the two 8×8 LED matrices used for the googly

eyes, ensuring proper integration, aesthetics, and structural stability.

### 19.1 Updated Sketch

Figure 15: Updated sketches

### 19.2 Updated Solidworks Design

Figure 16: Updated robot head design

### 19.3 Assembled Robot

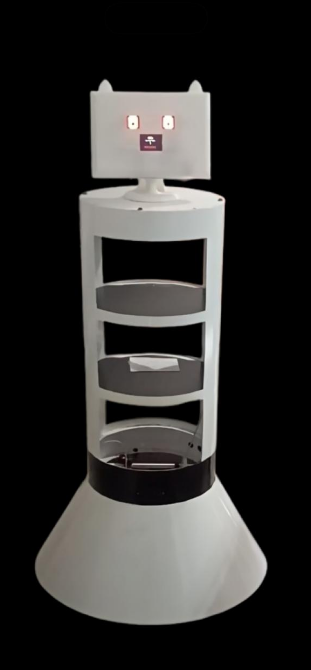
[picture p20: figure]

Figure 17: Assembled Robot

## 20 PCB

In the final design iteration, custom PCBs were designed and integrated into the robot, replacing the earlier use of development boards. During the last evaluation, the PCB had not yet been shipped to the team. After receiving the PCB, the team assembled and thoroughly debugged it, ensuring functionality and integration with all subsystems. This upgrade improved electrical robustness, reduced wiring complexity, and optimized space utilization within the mechanical structure.

## 21 PCB Pin Allocation

Table 9 shows the pin allocation of the main PCB in the final design. The allocation includes motor control pins, metal detecting sensor inputs, ultrasonic sensor connections, and power lines.

Figure 18: Pin Allocation

Pin | Function
1 | RM PU
2 | GND
3 | RM DR
4 | GND
5 | RM MF
6 | GND
7 | RM ALM
8 | GND
9 | LM PU
10 | GND
11 | LM DR
12 | GND
13 | LM MF
14 | GND
15 | LM ALM
16 | GND
17 | GND
18 | 3.3V
19-24 | Metal detecting 1-8
25 | PWM SONAR 1
26 | TRG SONAR 1
27 | GND
28 | 3.3V
29 | PWM SONAR 2
30 | TRG SONAR 2
31 | GND
32 | 3.3V
33 | PWM SONAR 3
34 | TRG SONAR 3
35 | GND
36 | 3.3V

Table 9: PCB pin allocation summary for the restaurant robot.

### 21.1 Bare and Assembled PCB

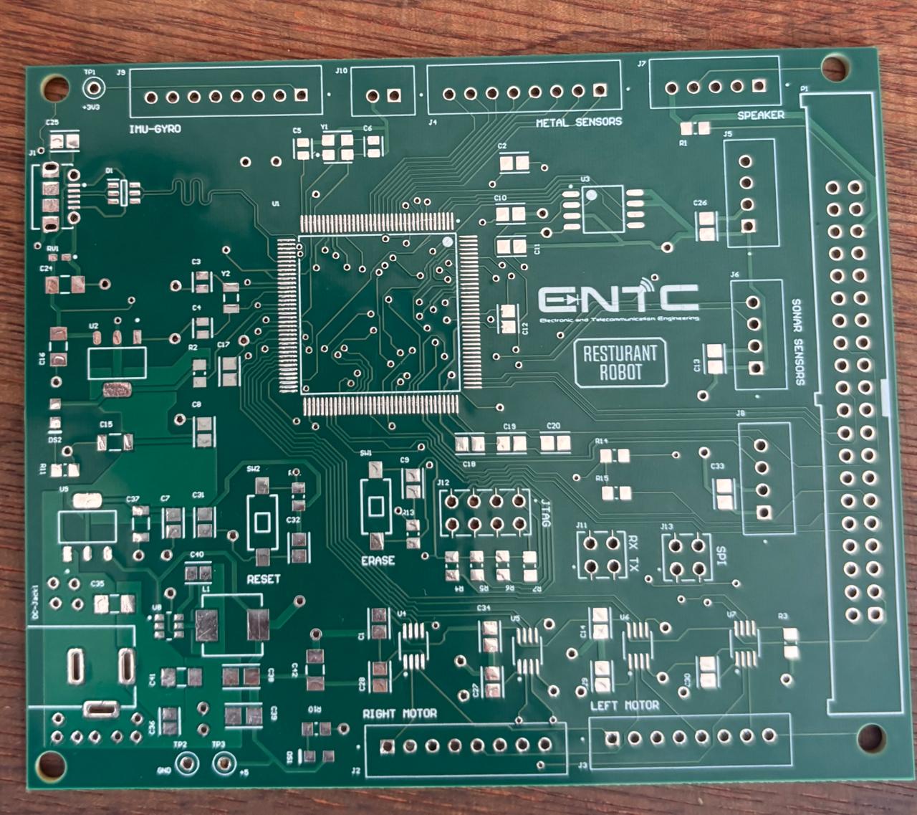
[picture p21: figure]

Figure 19: Bare Main PCB | Figure 20: Assembled Main PCB

### 21.2 Important Considerations and Changes due to Practical

### issues

Several important considerations were addressed in the final PCB implementation:

- Ultrasonic Sensor Array Spacing: In the ultrasonic sensor array PCB, only 6

out of the 8 headers were used. This was done to reduce the number of sensors to six, allowing sufficient spacing between adjacent sensors to minimize cross-interference and ensure reliable obstacle detection.

- IMU and Speaker System Exclusion: The IMU and speaker system were not

implemented in the final design due to time constraints and the complexity involved in their integration within the available project timeline.

- SWD (Serial Wire Debug) Interface: The SWD interface is implemented for

programming and real-time debugging of the microcontroller. We are Using the J-Link debugger, to upload firmware efficiently and perform in-circuit debugging.

- RS-232 Interface: RS-232 communication is used for serial data exchange between

the display and our main controller PCB. This interface is used for debugging, log-ging, and could be extended to connect to other RS-232-compatible modules. The RS-232 signals are level-shifted appropriately to ensure compatibility with external devices.

## 22 Acceleration Curve

There were no changes made to the acceleration curve design in the final iteration. The same S-curve profile was used to ensure smooth acceleration and deceleration of the robot.

1 | //S-curve
2 | // VMAX=75.0 , K=1.5 , X0=4.5
3 | float calculate_s_curve_velocity_acceleration(float t) {
4 | float exponent = -K * (t - X0); // Notice the minus here
5 | float exp_value = expf(exponent);
6 | float v = VMAX / (1.0f + exp_value);

7
8 | return v;
9 | } for (float t = 3.0f; t <= 8.0f; t += 0.1f) {
10 | Velocity = calculate_s_curve_velocity_acceleration(t);
11 | frequency = 40 * Velocity;
12 | processLineFollowing();
13 | //mdrive((40*Velocity),(40*Velocity));
14 | delay_ms(25); }

Listing 1: Acceleration Curve Code

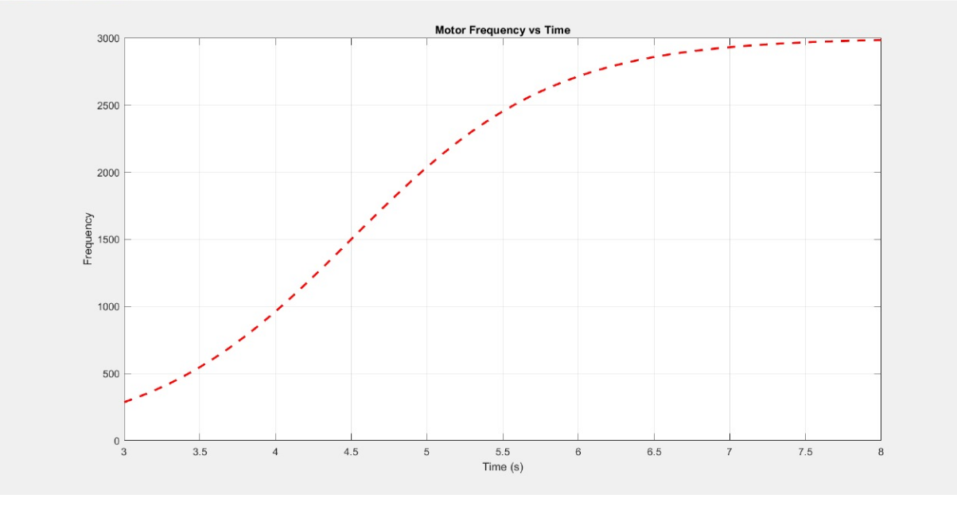
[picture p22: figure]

Figure 21: Acceleration curve

1 | //S-curve
2 | // VMAX=75.0 , K=1.5 , X0=4.5
3 | float calculate_s_curve_velocity_acceleration(float t) {
4 | float exponent = -K * (t - X0); // Notice the minus here
5 | float exp_value = expf(exponent);
6 | float v = VMAX / (1.0f + exp_value);

7
8 | return v;
9 | } for (float t = 3.0f; t <= 8.0f; t += 0.1f) {
10 | Velocity = calculate_s_curve_velocity_acceleration(t);

11 | frequency = 40 * Velocity;
12 | processLineFollowing();
13 | //mdrive((40*Velocity),(40*Velocity));
14 | delay_ms(25); }

Listing 2: Deceleration Curve Code

Figure 22: Deceleration curve

## 23 Firmware

Changes were made to the firmware in the final iteration to integrate the updated hardware components and display module. The updated code is provided in the project code base for reference.

## 24 Conclusion

The final iteration of the restaurant robot design represents a significant advancement in system integration, mechanical refinement, and electronic reliability. By replacing development boards with custom-designed PCBs, the team enhanced the robot’s stability, compactness, and wiring simplicity. Critical updates—including a power supply architecture, an efficient display solution using a 2.4” TFT touchscreen and 8×8 LED matrices,

and improved mechanical enclosure design—enabled the robot to function reliably in its intended environment.
Despite encountering practical limitations such as display damage, sensor spacing issues, and the exclusion of the IMU and speaker system, the team successfully adapted and optimized the robot within available time and resource constraints. The continued use of the S-curve acceleration profile ensured smooth and controlled motion, essential for a service robot operating in restaurant spaces.

Overall, the project demonstrates a strong application of electronic design realization principles and effective problem-solving under real-world constraints. The outcome is a functional, modular, and well-documented restaurant robot prototype that lays the groundwork for future improvements and potential deployment in hospitality environments.

## A Appendices

### A.1 Documents

- Nema 23 Motor and Driver:https://drive.google.com/drive/folders/1t_

PN02JcCgiCsATQyiluq-kj0ZTv335-?usp=drive_link (https://drive.google.com/drive/folders/1t_PN02JcCgiCsATQyiluq-kj0ZTv335-?usp=drive_link)

- AO2 | PWM | Ultrasonic | Sensors: | https://drive.google.com/drive/

folders/1_Xdv5ZsOF8AB279o9QYAdrCsSYbcH0dw?usp=drive_link (https://drive.google.com/drive/folders/1_Xdv5ZsOF8AB279o9QYAdrCsSYbcH0dw?usp=drive_link)

- Proximity | Sensors: | https://drive.google.com/drive/folders/

1keqV7BNKRRuUt0pEe417E9VMuuxMAJQu?usp=drive_link (https://drive.google.com/drive/folders/1keqV7BNKRRuUt0pEe417E9VMuuxMAJQu?usp=drive_link)

- 7-inch TFT LCD Display: https://drive.google.com/drive/folders/

14D8buxf1hrKpHv2f4uz1sQXVDi9iKZ4L?usp=drive_link (https://drive.google.com/drive/folders/14D8buxf1hrKpHv2f4uz1sQXVDi9iKZ4L?usp=drive_link)

- SAM3X8E | MCU: | https://drive.google.com/file/d/

1gG4gJJS6T9XMbzaYF70B0jIM091cdNFk/view?usp=drive_link (https://drive.google.com/file/d/1gG4gJJS6T9XMbzaYF70B0jIM091cdNFk/view?usp=drive_link)

- Wheel: | https://drive.google.com/drive/folders/

1SpT7xqD51tSb7tsyiDhPFohJYaKiCV0P?usp=drive_link (https://drive.google.com/drive/folders/1SpT7xqD51tSb7tsyiDhPFohJYaKiCV0P?usp=drive_link)

### A.2 Full Schematic Diagrams

This section contains the schematic diagrams of the 2 PCBs, illustrating the interconnec-tions between all major components and subsystems used in the restaurant robot.

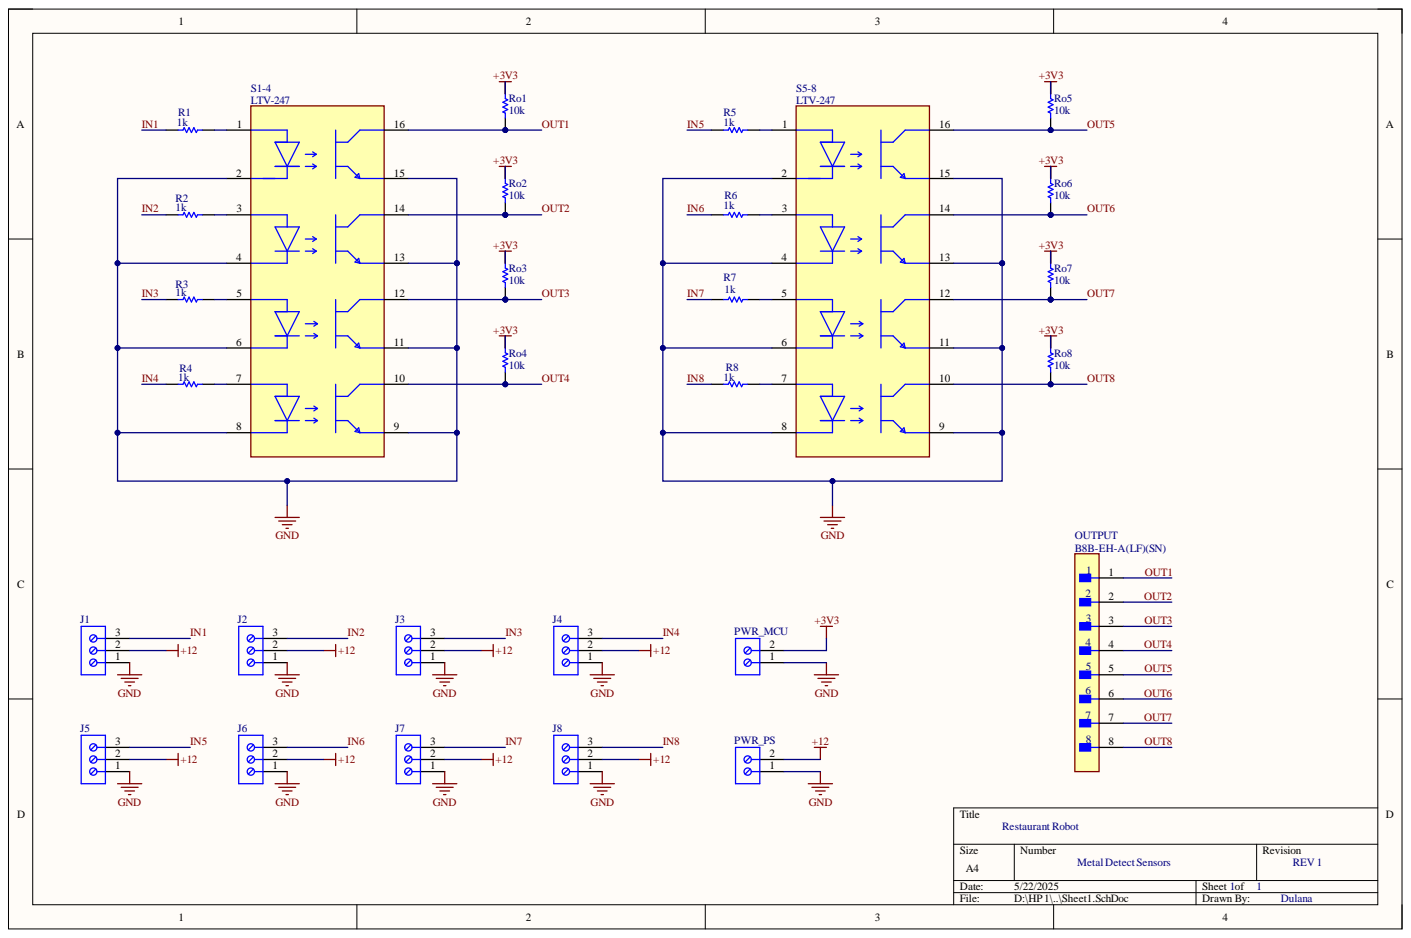
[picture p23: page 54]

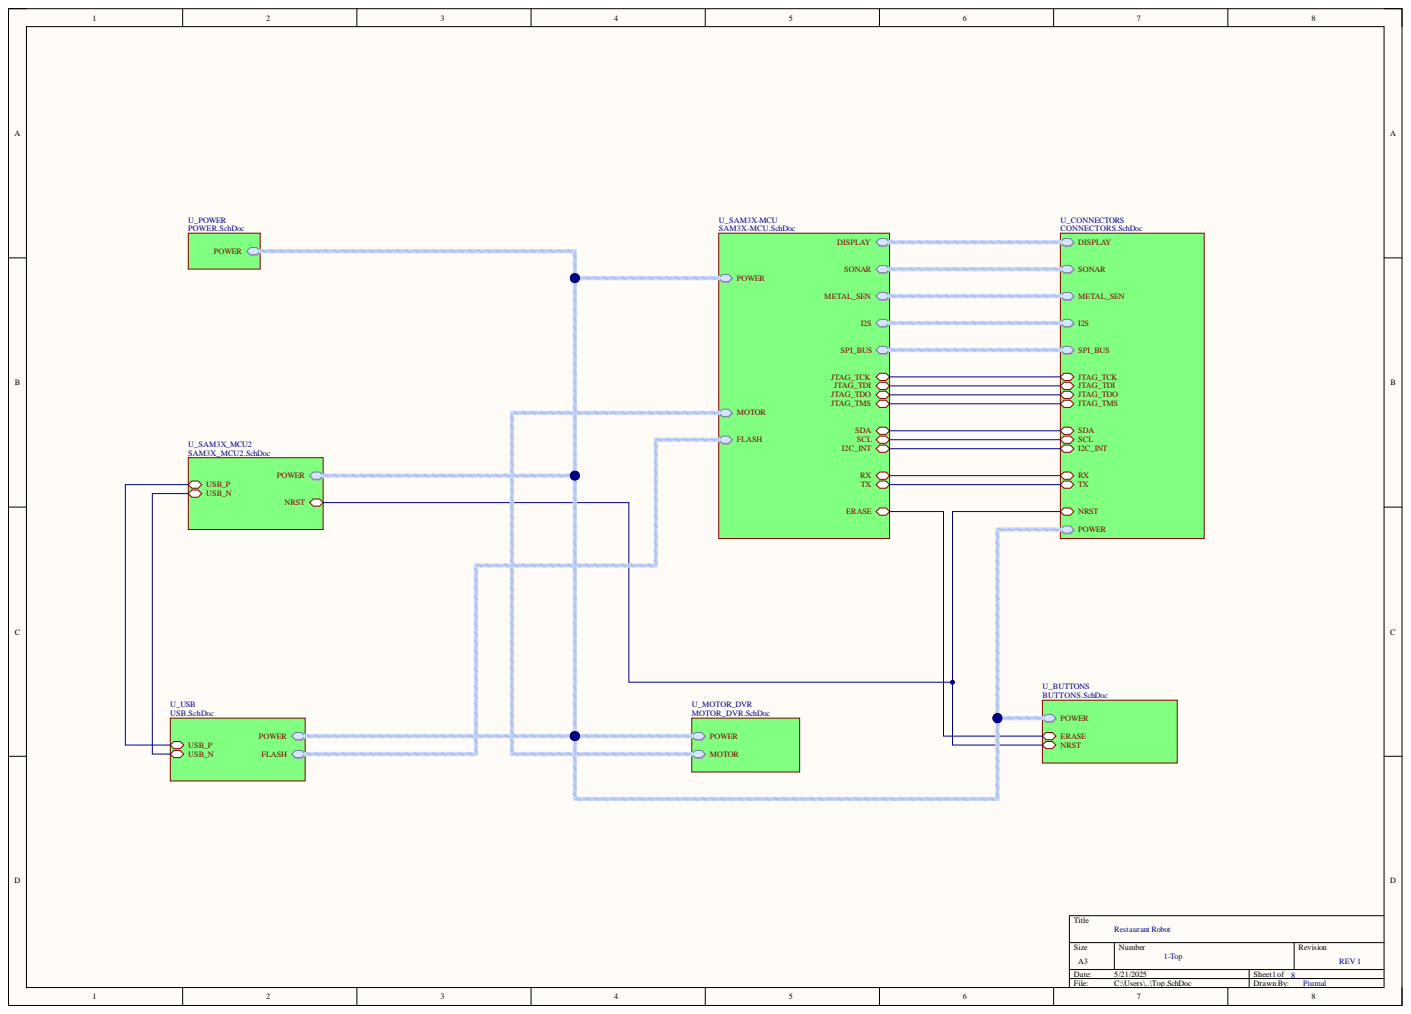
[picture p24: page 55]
Title; Size; Number; Revision; Date:; Sheet of; File:; C:\Users\..\Top.SchDoc; Drawn By:; MOTOR; FLASH; SONAR; METAL_SEN; DISPLAY; JTAG_TCK JTAG_TDI JTAG_TDO JTAG_TMS; ERASE; SDA SCL I2C_INT; SPI_BUS; POWER; U_SAM3X-MCU SAM3X-MCU.SchDoc; USB_P USB_N; NRST; U_SAM3X_MCU2 SAM3X_MCU2.SchDoc; ERASE NRST; U_BUTTONS BUTTONS.SchDoc; U_MOTOR_DVR MOTOR_DVR.SchDoc; USB_P; USB_N; U_USB USB.SchDoc; U_POWER POWER.SchDoc; U_CONNECTORS CONNECTORS.SchDoc; 1-Top; Piumal; Restaurant Robot; REV 1

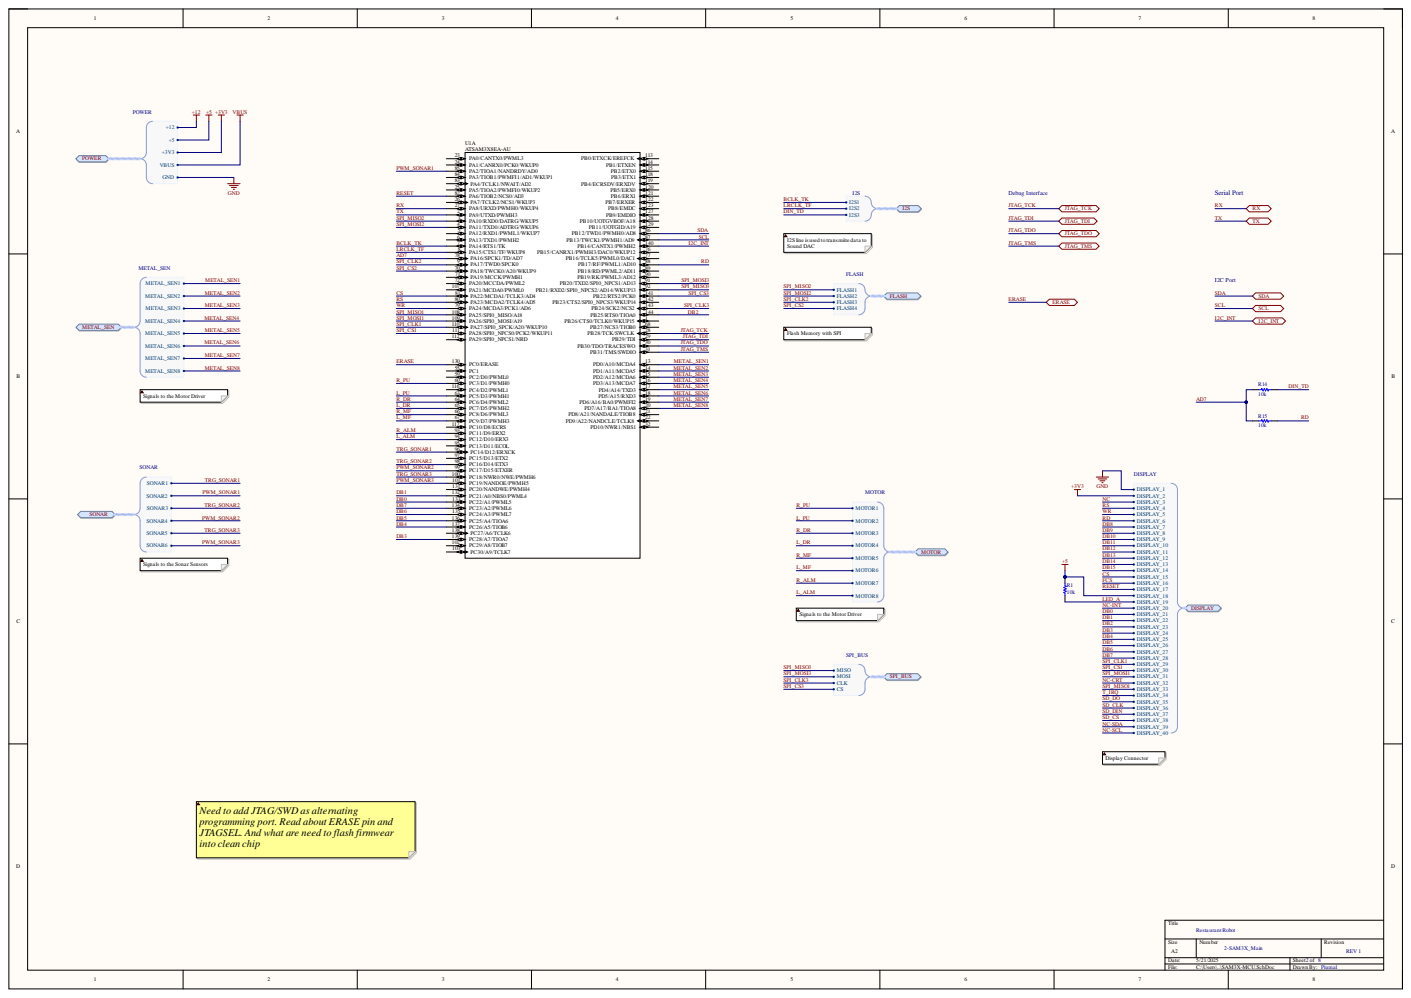
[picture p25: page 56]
Title; Size; Number; Revision; Date:; Sheet of; File:; C:\Users\..\SAM3X-MCU.SchDoc; Drawn By: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

I2Sline is used to transmiite data to
Sound DAC

Flash Memory with SPI

Signals to the Motor Driver

Signals to the Sonar Sensors

Need to add JTAG/SWD as alternating
programming port. Read about ERASE pin and
JTAGSEL. And what are need to flash firmwear
into clean chip

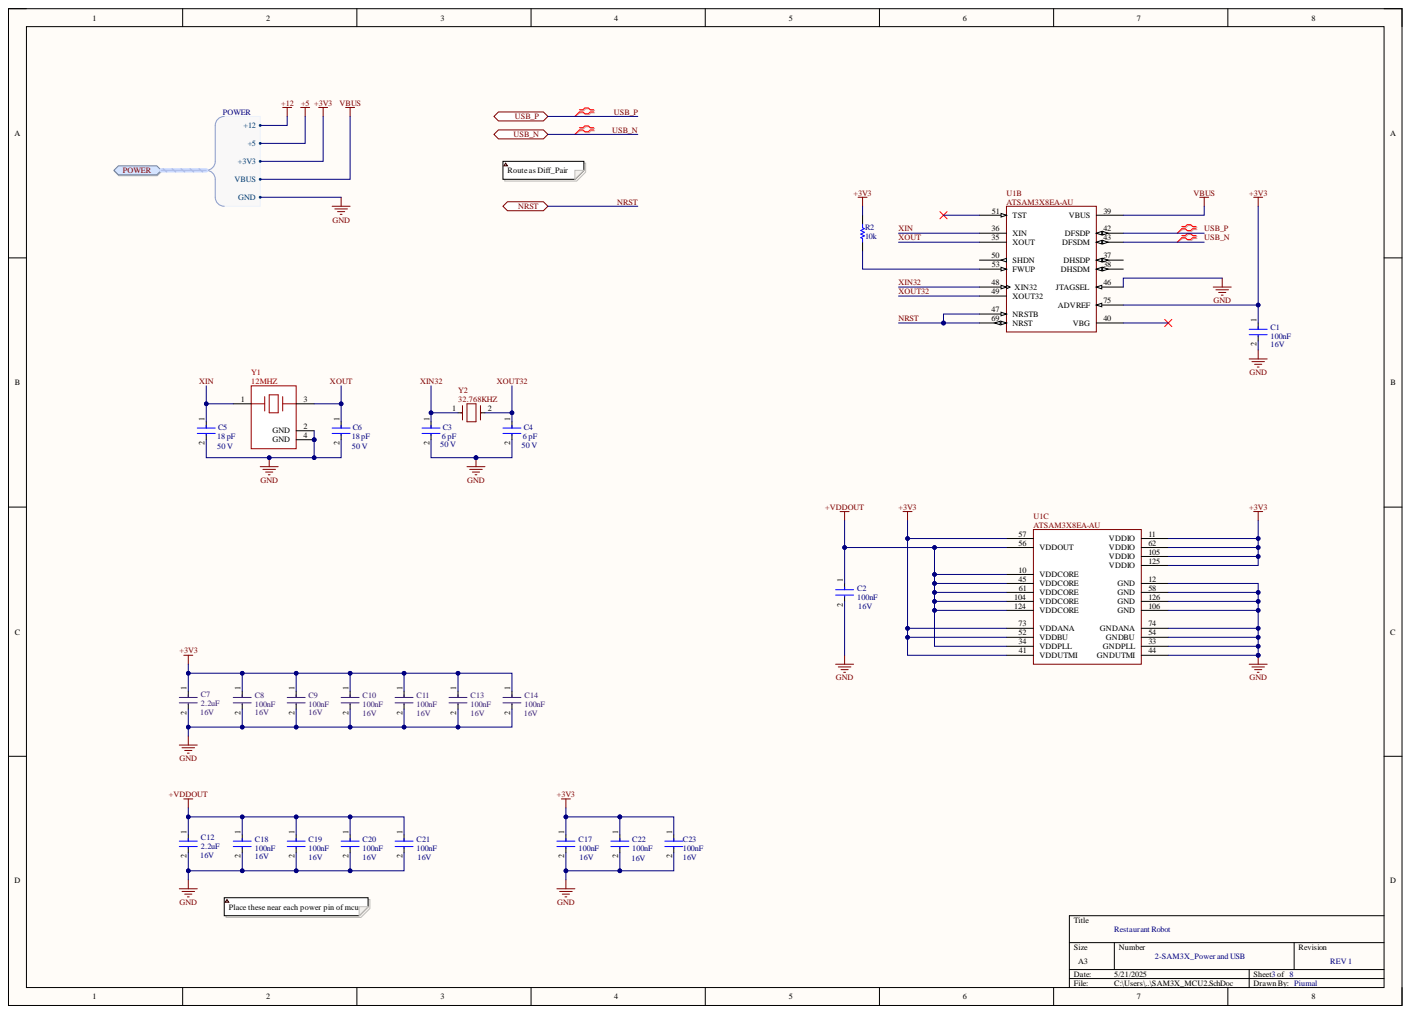
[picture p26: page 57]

Place these near each power pin of mcu

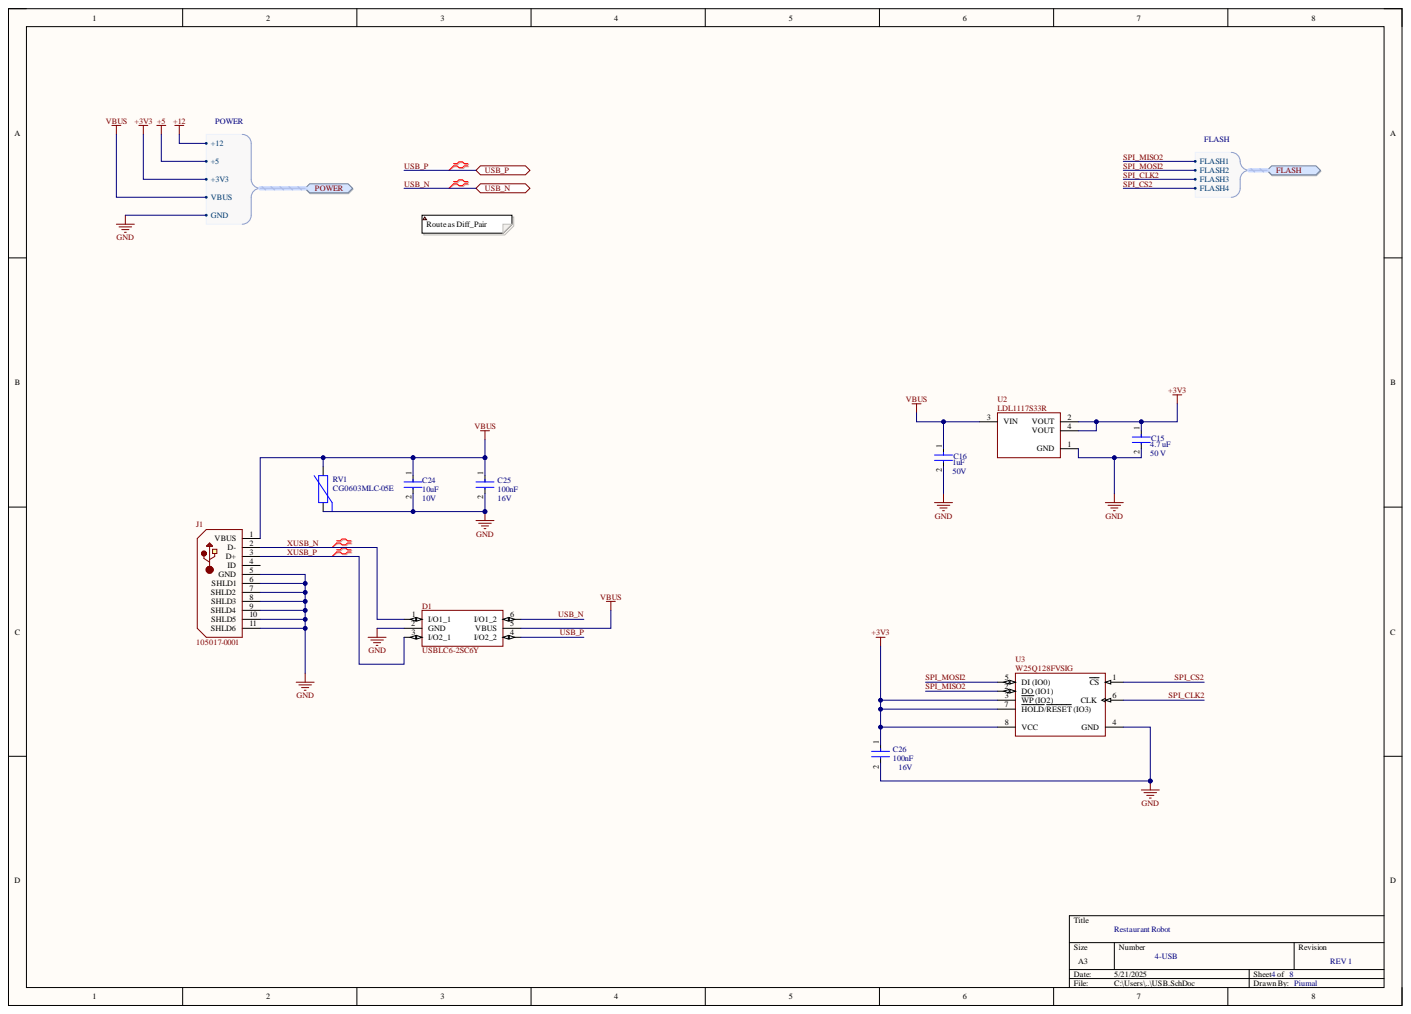
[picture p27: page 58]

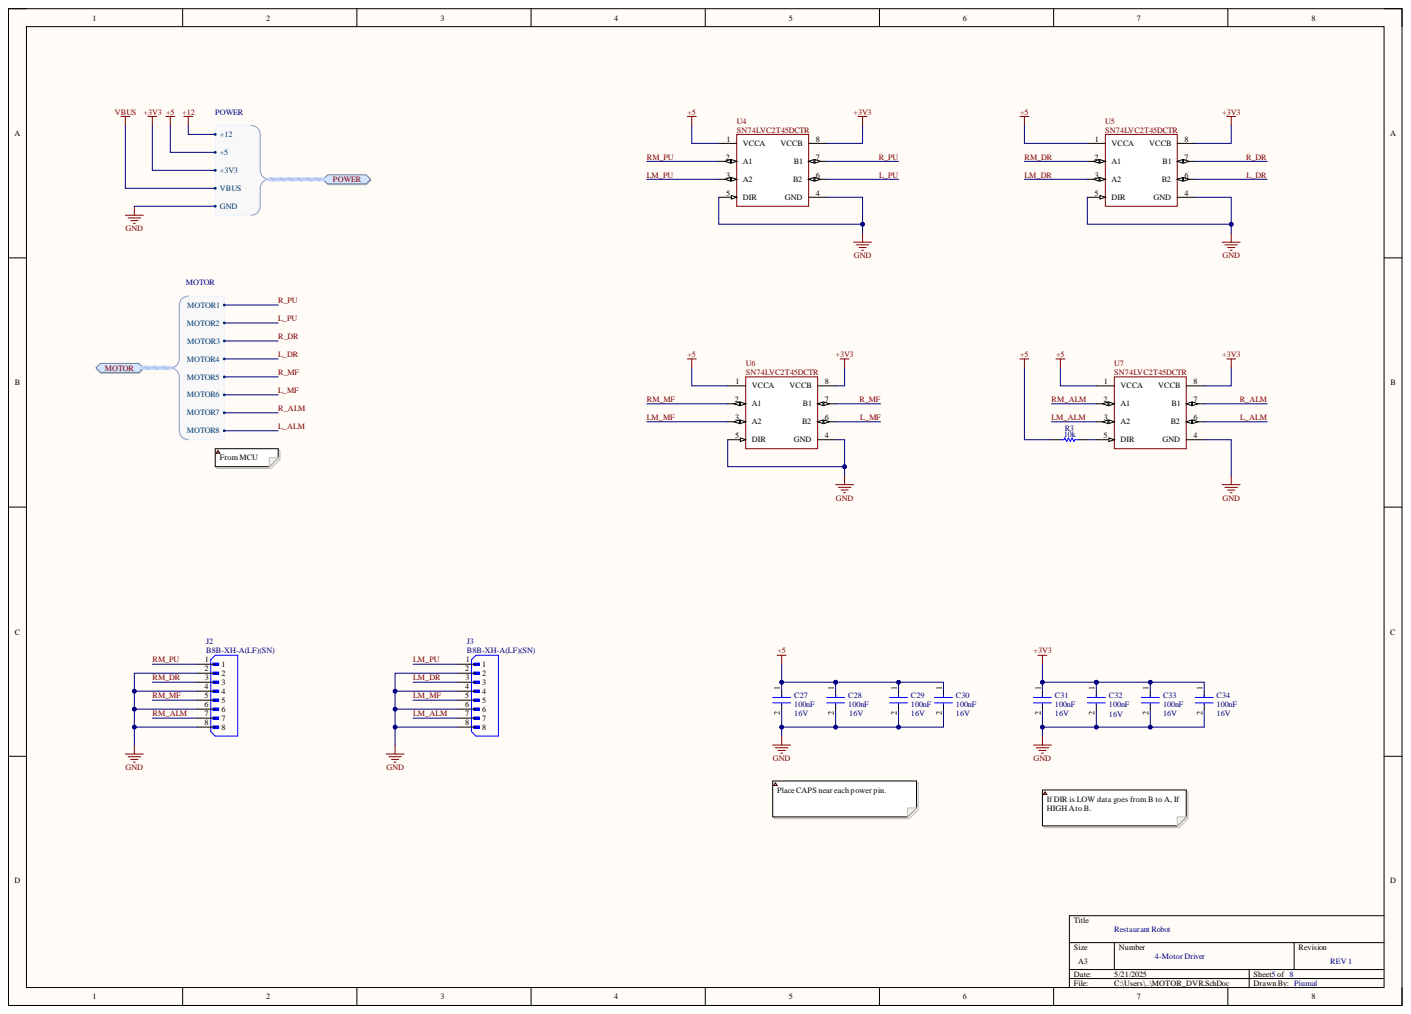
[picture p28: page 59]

PlaceCAPS near each power pin.

If DIR is LOW data goes from B to A, If
HIGH Ato B.

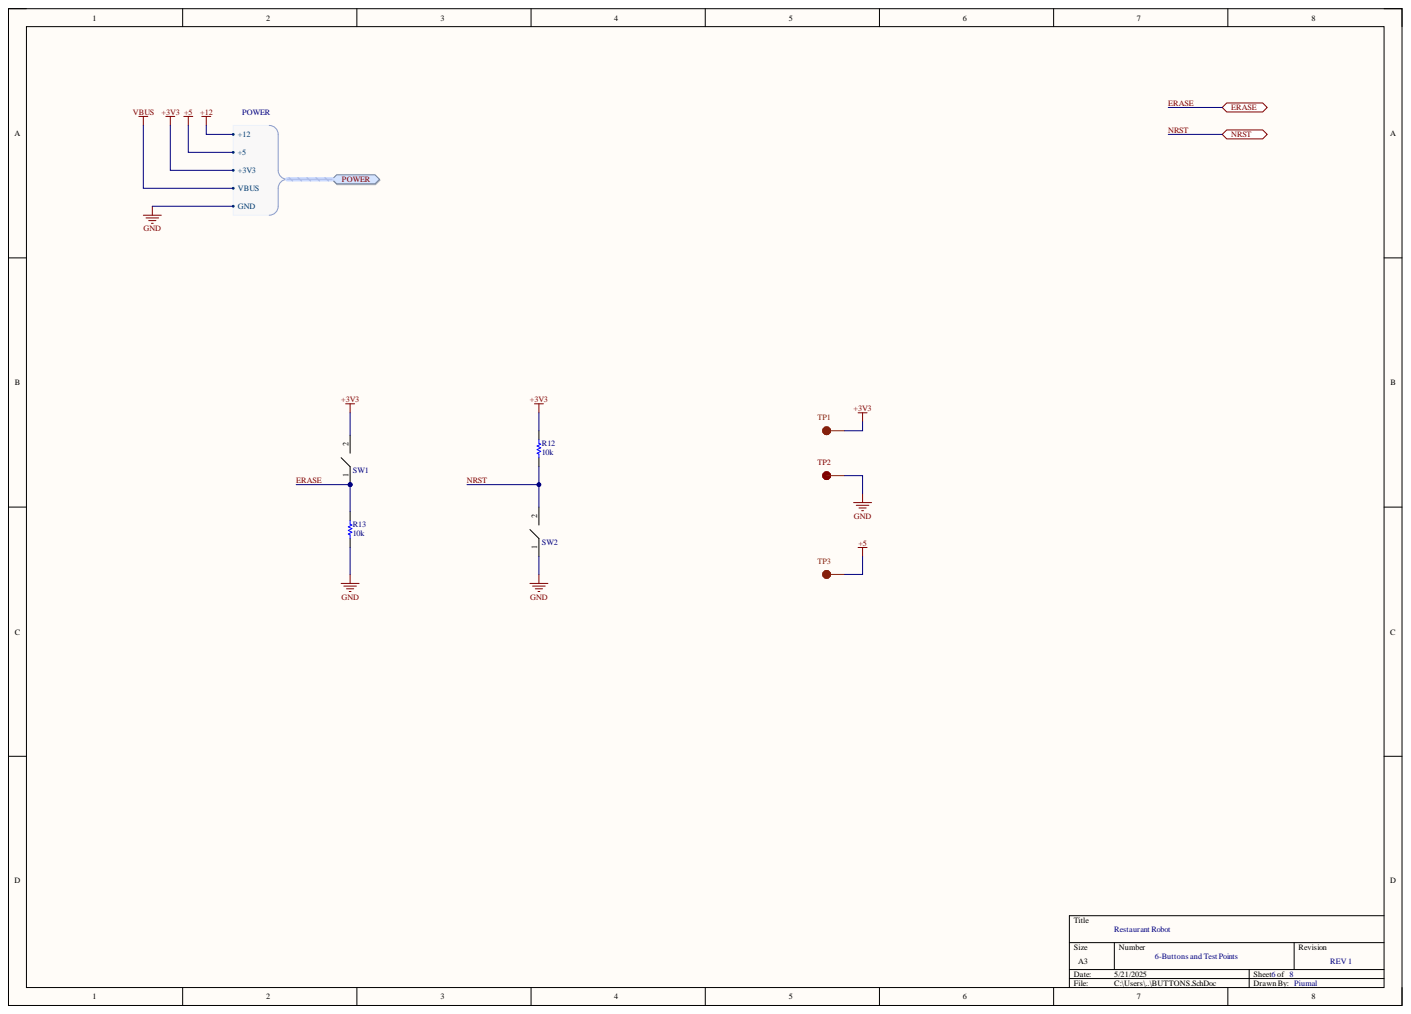
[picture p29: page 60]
Title; Size; Number; Revision; Date:; Sheet of; File:; C:\Users\..\BUTTONS.SchDoc; Drawn By:; GND; ERASE; NRST; VBUS; POWER; Piumal; REV 1; Restaurant Robot

6-Buttons and Test Points

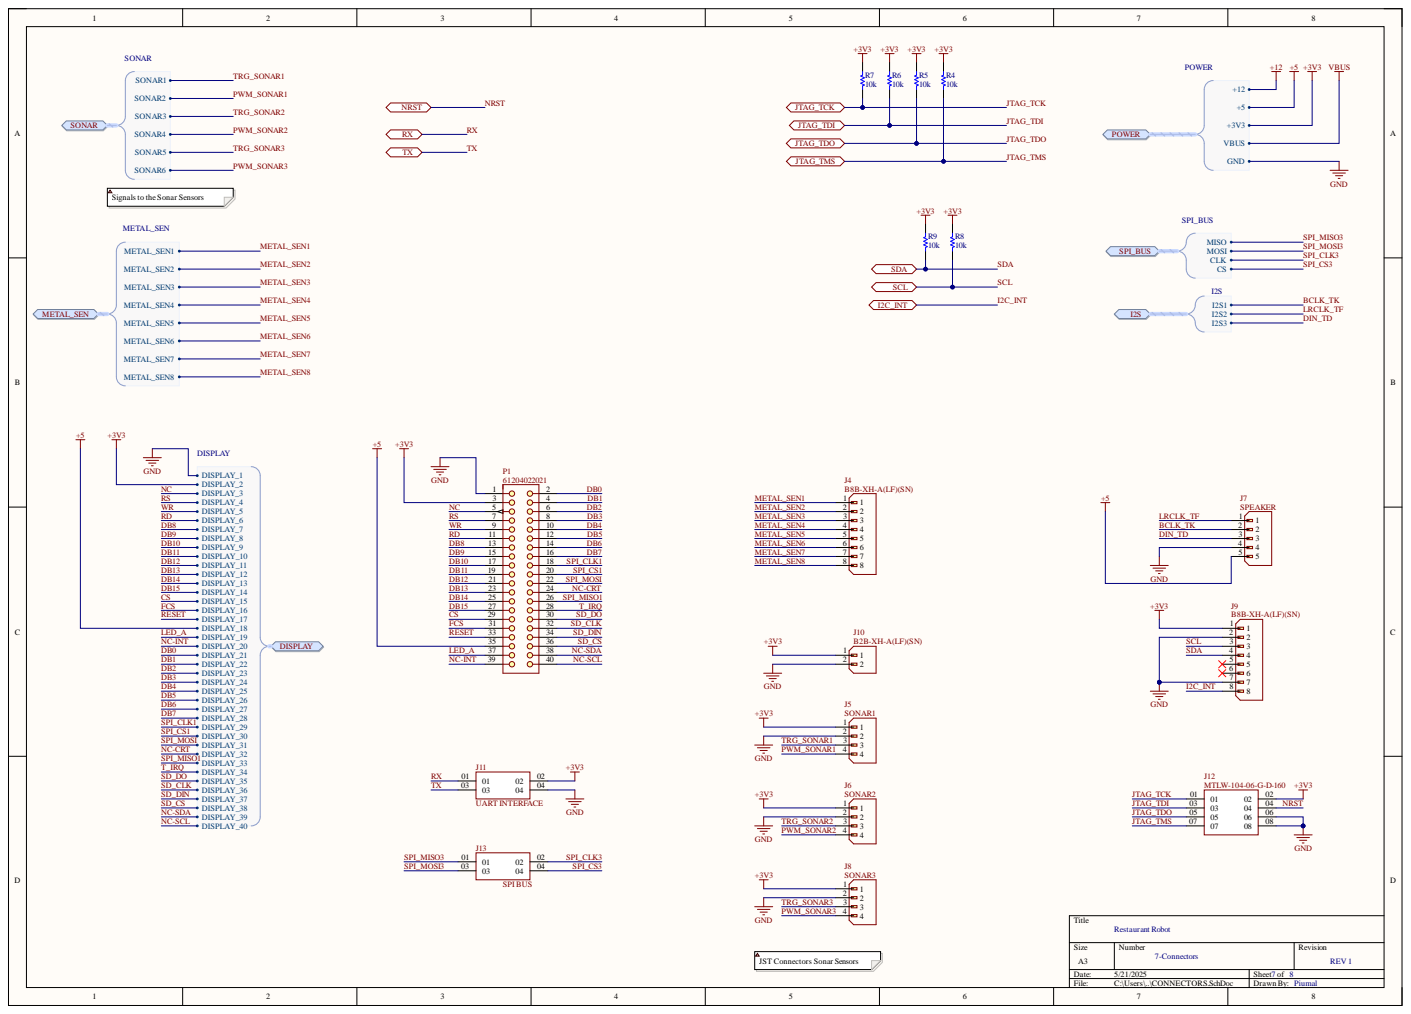
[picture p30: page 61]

JST Connectors Sonar Sensors

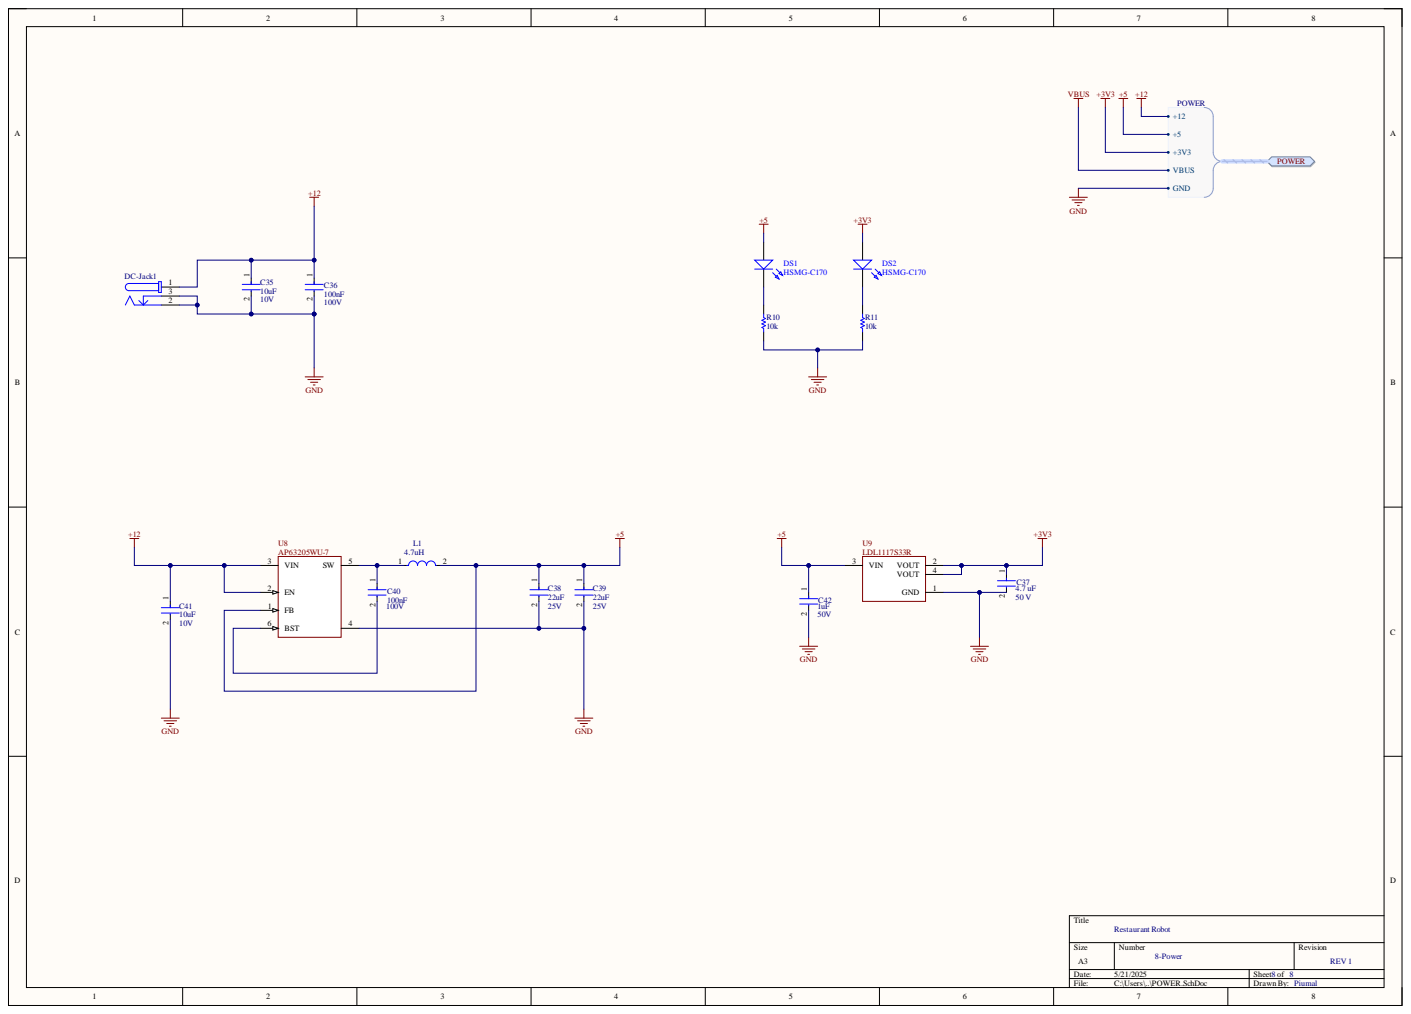
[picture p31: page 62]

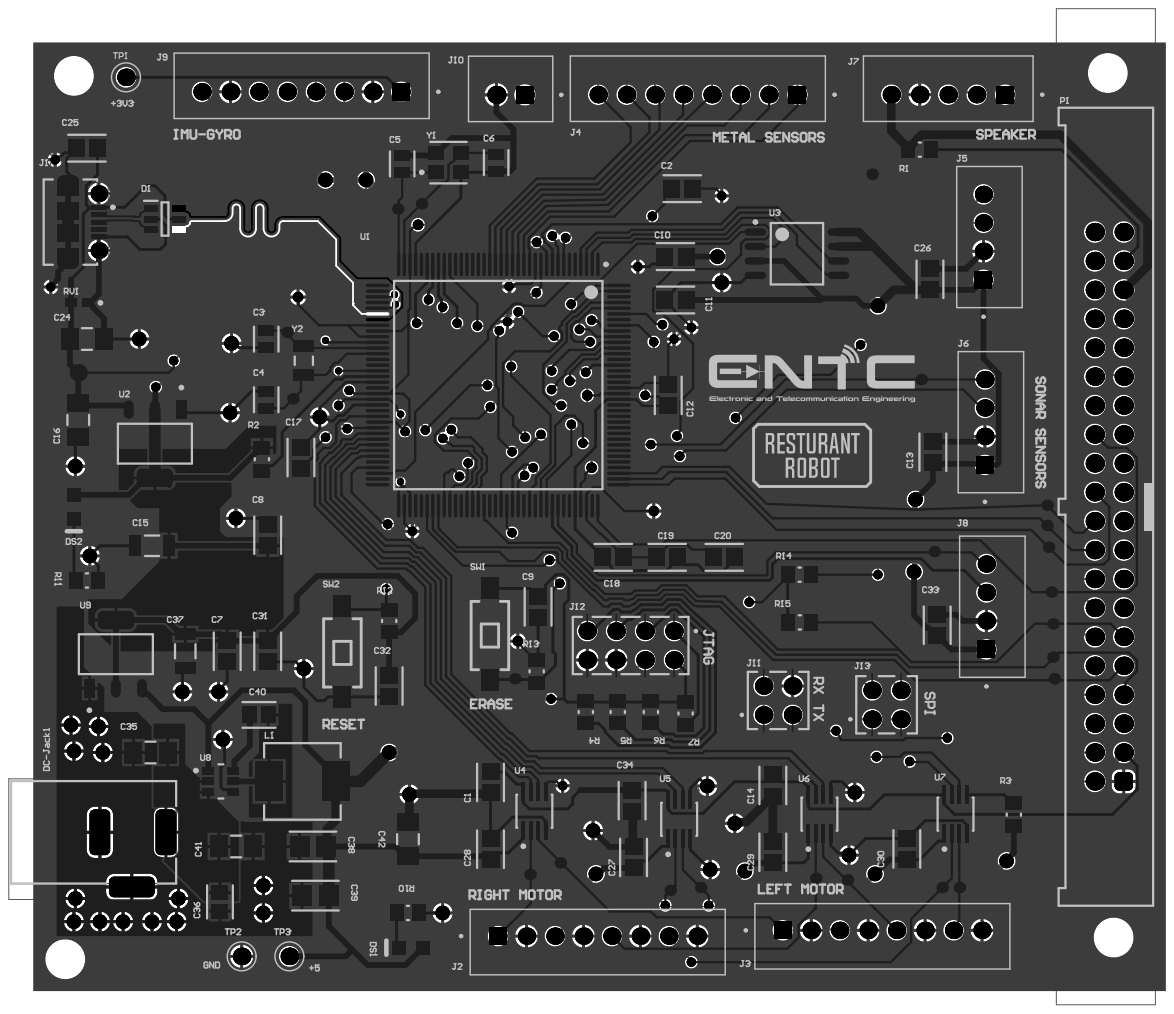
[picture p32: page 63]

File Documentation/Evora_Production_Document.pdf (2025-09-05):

# Restaurant Service Robot

# Production Manual


Restaurant Robot | Design Report

## Contents

1 Introduction | 3
2 Bill of Materials (BOM) | 3
3 Mechanical Assembly Instructions | 4
4 Electronic Assembly Instructions | 5
5 PCB Design Details | 7
6 Firmware and Upload Procedure | 8
7 Calibration and Configuration | 9
8 Quality Control and Checklists | 9

9 Packaging and Shipping | 10
10 Appendices | 10

## 1 Introduction

### 1.1 Purpose of the Document

This document serves as the comprehensive production guide for the Restaurant Robot developed under the EN2160 – Electronic Design Realization course. It provides all the technical information necessary for reproducing, assembling, wiring, programming, and testing the robot. The documentation is intended to support manufacturing, maintenance, and future development activities.

### 1.2 Target Audience

This document is intended for:

- Engineers and technicians involved in hardware assembly and PCB manufacturing
- Personnel responsible for mechanical fabrication and system integration
- Developers maintaining or modifying the firmware and software systems
- Future project teams or manufacturers looking to replicate or upgrade the robot

### 1.3 Project Summary

The Restaurant Robot is an autonomous indoor service platform designed to transport food and interact with customers in restaurant environments. Inspired by commercial service robots like BellaBot, the system integrates mechanical mobility, sensor-driven navigation, user interaction via a touch display, and modular subsystems communicating through RS-232.
The robot consists of a fabricated steel and plastic chassis with multiple food trays, a SAM3X8E microcontroller at its core, custom PCB for electronics integration, and dedicated firmware for navigation and interaction.

## 2 Bill of Materials (BOM)

The table below summarizes the key electronic components used in the PCB design of the Restaurant Robot.

Component | Designators | Description | Qty
100nF Capacitors | C1–C2, C8–C34 | MLCC 0805, X7R 16V | 25
12pF Capacitors | C3–C6 | MLCC 0805, C0G | 4
2.2uF Capacitors | C7, C12 | MLCC 0805, X5R | 2
4.7uF Capacitors | C15, C37 | MLCC 1206, X7R | 2
10uF Capacitors | C24, C35, C41 | MLCC 1206, X5R | 3
22uF Capacitors | C38, C39 | MLCC 1206, X5R | 2
Resistors 10k | R1–R15 | Chip Resistors 0805 | 15
Microcontroller | U1 | ATSAM3X8E LQFP-144 | 1
Voltage Regulators | U2, U9 | LDL1117 3.3V, SOT-223 | 2
Flash Memory | U3 | W25Q128FVSIG, 128Mbit SPI | 1
Level Shifters | U4–U7 | SN74LVC2T45, 2-bit dual | 4
Buck Converter | U8 | AP63205WU-7, 5V 2A | 1
Crystals | Y1, Y2 | 12MHz, 32.768kHz | 2
USB Connector | J1 | Micro-USB B, SMD | 1
Connectors | J2–J13 | JST/XH 2–8 pin | 12
Inductor | L1 | IHLP2525, 4.7uH | 1
LEDs | DS1, DS2 | Green SMD LED | 2
Test Points | TP1–TP5 | Red PhosBronze THM | 5
Push Buttons | SW1, SW2 | Tactile SPST-NO | 2
ESD Protection | RV1 | TVS Diode / ESD Chip | 1
DC Jack | P1 | Barrel Jack Connector | 1

Table 1: Simplified Bill of Materials for Restaurant Robot PCB

## 3 Mechanical Assembly Instructions

This section outlines the step-by-step procedure for assembling the mechanical components of the Restaurant Robot. It includes subassemblies, required tools, and special precautions to ensure mechanical integrity and modularity.

### 3.1 Exploded View Diagrams

Refer to the attached exploded view drawings from the SolidWorks model for a visual guide of the mechanical structure. Each major part is labeled and cross-referenced with the Bill of Materials (BOM).

### 3.2 Chassis and Frame Assembly

1. Begin with the steel base frame.
2. Fix the motor mounting brackets onto the rear side using L-angle supports. Align the holes with pre-drilled motor baseplates.
3. Mount the two drive wheels on either side, connected to the NEMA 23 motors.

4. Use vibration-dampening rubber pads under each motor mount to reduce mechanical noise.

### 3.3 Tray and Mounting Installation

1. Slide the metal trays into their designated rails. Each tray should support up to 5 kg.
2. Ensure adequate spacing between trays for dish clearance.

### 3.4 Enclosure Assembly

1. Attach the plastic display cover on the top of the robot.
2. Install the 7.0” TFT LCD panel inside the enclosure with proper alignment to the front window.
3. Add wire management clips inside the enclosure to route power and signal lines cleanly.
4. Close the top housing with the plastic enclosure cover. Fix it with screws or clips, ensuring accessibility for maintenance.

### 3.5 Assembly Notes

- Double-check alignment before tightening screws to prevent misalignment of rotat-

ing parts.

- Use thread-lock where necessary to reduce loosening due to vibration.
- Avoid overtightening plastic parts to prevent cracking.
- Conduct a final shake-test to identify any loose mechanical parts.

## 4 Electronic Assembly Instructions

This section provides step-by-step instructions for assembling the electronic components of the robot. It includes guidance for installing the custom PCB, wiring external modules, and ensuring proper power and signal connections.

### 4.1 PCB Population Guide

1. Place the PCB on a static-free work surface.
2. Begin with the smallest and lowest-profile components first (e.g., resistors, capacitors).
3. Solder the ICs, connectors, and regulators as per the silkscreen labels and the PCB assembly diagram.
4. Install the RS-232 transceiver, voltage regulators, and power filtering components carefully to avoid overheating.
5. Visually inspect all solder joints and verify for any cold joints or solder bridges.

### 4.2 Wiring Diagrams and Connectors

- Use labeled jumper wires or ribbon cables to connect external modules to the ap-

propriate headers on the PCB.

- Secure connectors with locking clips or heat-shrink tubing where applicable.
- Follow the wiring as shown in the reference image.


Figure 1: Reference wiring diagram of the PCB with peripherals

### 4.3 Sensor and Actuator Integration

1. Mount the metal detection sensors and obstacle detection modules at their designated locations on the frame.
2. Run wires back to the PCB using cable sleeves or conduits to avoid tangling with moving parts.
3. Connect sensor outputs to labeled analog/digital input headers on the PCB.
4. Connect the NEMA 23 stepper motors to the motor driver output terminals.

### 4.4 Display and Microcontroller Mounting

1. Mount the 7.0” TFT LCD to the front panel using standoffs and M4 screws.
2. Connect the 16-bit parallel interface ribbon cable between the display and the microcontroller.
3. Install the SAM3X8E board onto the designated standoffs inside the enclosure.
4. Double-check the microcontroller power, ground, and programming interface connections.

### 4.5 Safety Checks Before Power-Up

- Verify all ground connections are secure.
- Confirm no shorts between power rails and ground.
- Ensure all high-current paths use proper gauge wires.
- Inspect for correct orientation of all polarized components (diodes, capacitors, ICs).

## 5 PCB Design Details

### 5.1 Board Layout

There are 2 PCBs for this robot. Main PCB and the PCB for Proximity Sensors. The Main PCB is designed to be compact and modular, housing the SAM3X8E microcontroller, motor driver interface, power regulators, RS-232 transceiver, and connectors for display, sensors, and audio. Each functional section is isolated for signal clarity.
The main PCB is a 4-layer board.
This stackup enhances EMI performance, reduces ground bounce, and allows better thermal dissipation for power components.

### 5.2 Gerber Files and Manufacturing Notes

Gerber files were exported for a 4-layer stack with impedance control enabled. The drill file, paste mask, and silkscreen layers are included. Manufacturing parameters:

- Minimum trace width/spacing: 6 mil / 6 mil
- Minimum via size: 0.3 mm
- Board dimensions: approx. 100 mm × 80 mm
- Soldermask: Green, Top and Bottom
- Silkscreen: Top layer only

## 6 Firmware and Upload Procedure

### 6.1 Microcontroller Setup

The main controller used in this project is the ATSAM3X8E ARM Cortex-M3 microcontroller. It handles sensor data acquisition, display management, RS-232 communication, and actuator control. The microcontroller is mounted on a custom PCB with access to UART, SPI, I2C, and JTAG interfaces. Power is supplied via an onboard 3.3V regulator, and reset/erase pins are routed to pushbuttons for programming convenience.

### 6.2 Flashing Instructions

Firmware was compiled using a standard ARM-GCC toolchain and flashed to the device using an RS-232 interface. In most cases, the following general steps were followed:

1. Connect the microcontroller to the PC using a standard RS-232 serial cable.
2. Press and hold the ERASE and NRST buttons in sequence to enter bootloader or programming mode.
3. Use a flashing utility (e.g., BOSSA, Atmel Studio, or SAM-BA) to upload the

compiled ‘.bin‘ or ‘.hex‘ file.

4. Once uploaded, perform a reset to run the firmware.

Details may vary based on the specific programmer used and development environment.

### 6.3 Configuration Parameters

Most configuration parameters such as RS-232 baud rate, sensor thresholds, and display mode settings are defined within the firmware source code. These values can be modified in the configuration header files or adjusted at compile-time.

### 6.4 Assembly Drawing with Labels

All components are labeled with designators on the silkscreen: resistors (R1–R15), capacitors (C1–C42), connectors (J1–J13), ICs (U1–U9), and jumpers. Component placement ensures easy soldering and access to debugging headers (e.g., JTAG, ERASE, NRST).

## 7 Calibration and Configuration

### 7.1 Sensor Calibration

The metal detection sensors and ultrasonic distance sensors are tested using known metallic paths and fixed obstacles. Calibration includes:

- Verifying detection range consistency
- Checking for electromagnetic interference on signal lines

## 8 Quality Control and Checklists

### 8.1 Visual Inspection Checklist

- All components correctly placed and soldered
- No visible solder bridges
- Polarized components (diodes, caps, ICs) in correct orientation
- PCB not warped or scratched

### 8.2 Continuity Test Procedure

1. Set multimeter to continuity mode
2. Probe VCC and GND traces for shorts
3. Verify connection from SAM3X8E pins to connectors (e.g., TX/RX to RS-485, DB pins to display)
4. Confirm power supply paths: 12V input, 5V/3.3V regulators

### 8.3 Functional Test Checklist

- Display powers on and shows interface
- Metal sensor detects aluminum strip
- Ultrasonic sensor detects hand within 30 cm
- Motors respond to direction commands
- RS-232 transmits and receives messages correctly

## 9 Packaging and Shipping

### 9.1 Safe Packaging Guidelines

To protect the robot during transport:

- Place robot in ESD-safe foam-lined box
- Secure moving parts (wheels, trays) with zip ties or tape
- Cover display screen with plastic film
- Label the box with “Fragile” and “This Side Up”

## 10 Appendices

### 10.1 3D Models and Drawings

Figure 2 shows the exploded view of the assembled robot, illustrating the mechanical structure, component placement, and enclosure design based on the SolidWorks model.


Figure 2: Exploded view of the restaurant robot assembly

### 10.2 Source Code Repository Link

The complete source code, including firmware, hardware schematics and PCB layout files for the Restaurant Robot project, is hosted on GitHub and can be accessed using the following link:

- https://github.com/YourUsername/restaurant-robot (https://github.com/ThilinaNirmalBandara/Restaurant-Robot-Evora)

### 10.3 Data Sheets and Relevant Documents

- Nema 23 Motor and Driver:https://drive.google.com/drive/folders/1t_

PN02JcCgiCsATQyiluq-kj0ZTv335-?usp=drive_link (https://drive.google.com/drive/folders/1t_PN02JcCgiCsATQyiluq-kj0ZTv335-?usp=drive_link)

- AO2 | PWM | Ultrasonic | Sensors: | https://drive.google.com/drive/

folders/1_Xdv5ZsOF8AB279o9QYAdrCsSYbcH0dw?usp=drive_link (https://drive.google.com/drive/folders/1_Xdv5ZsOF8AB279o9QYAdrCsSYbcH0dw?usp=drive_link)

- Proximity | Sensors: | https://drive.google.com/drive/folders/

1keqV7BNKRRuUt0pEe417E9VMuuxMAJQu?usp=drive_link (https://drive.google.com/drive/folders/1keqV7BNKRRuUt0pEe417E9VMuuxMAJQu?usp=drive_link)

- 7-inch TFT LCD Display: https://drive.google.com/drive/folders/

14D8buxf1hrKpHv2f4uz1sQXVDi9iKZ4L?usp=drive_link (https://drive.google.com/drive/folders/14D8buxf1hrKpHv2f4uz1sQXVDi9iKZ4L?usp=drive_link)

- SAM3X8E | MCU: | https://drive.google.com/file/d/

1gG4gJJS6T9XMbzaYF70B0jIM091cdNFk/view?usp=drive_link (https://drive.google.com/file/d/1gG4gJJS6T9XMbzaYF70B0jIM091cdNFk/view?usp=drive_link)

- Wheel: | | https://drive.google.com/drive/folders/

1SpT7xqD51tSb7tsyiDhPFohJYaKiCV0P?usp=drive_link (https://drive.google.com/drive/folders/1SpT7xqD51tSb7tsyiDhPFohJYaKiCV0P?usp=drive_link)

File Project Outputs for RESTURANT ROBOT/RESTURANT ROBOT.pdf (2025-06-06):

Line # | Comment | Description | Designator | Revision ID | Revision Status | Quantity | Manufacturer 1 | Manufacturer Part Number 1 | Manufacturer Lifecycle 1 | Supplier 1 | Supplier Part Number 1 | Supplier Unit Price 1 | Supplier Subtotal 1
| CL21B104KOANNNC | CL21 Series 0805 100nF 16V ±10% Tolerance X7R Multilayer Ceramic Chip Capacitor | C1 | | | | 1
| CL21B104KOANNNC | CL21 Series 0805 100nF 16V ±10% Tolerance X7R Multilayer Ceramic Chip Capacitor | C2 | | | | 1
| C0805C120J5GACTU | CAP CER 12PF 50V C0G/NP0 0805 | C3 | | | | 1
| C0805C120J5GACTU | CAP CER 12PF 50V C0G/NP0 0805 | C4 | | | | 1
| C0805C120J5GACTU | CAP CER 12PF 50V C0G/NP0 0805 | C5 | | | | 1
| C0805C120J5GACTU | CAP CER 12PF 50V C0G/NP0 0805 | C6 | | | | 1
| CL21A225KOFNNNG | CL21 Series 0805 2.2uF 16V ±10% Tolerance X5R Multilayer Ceramic Chip Capacitor | C7 | | | | 1
| CL21B104KOANNNC | CL21 Series 0805 100nF 16V ±10% Tolerance X7R Multilayer Ceramic Chip Capacitor | C8 | | | | 1
| CL21B104KOANNNC | CL21 Series 0805 100nF 16V ±10% Tolerance X7R Multilayer Ceramic Chip Capacitor | C9 | | | | 1
| CL21B104KOANNNC | CL21 Series 0805 100nF 16V ±10% Tolerance X7R Multilayer Ceramic Chip Capacitor | C10 | | | | 1
| CL21B104KOANNNC | CL21 Series 0805 100nF 16V ±10% Tolerance X7R Multilayer Ceramic Chip Capacitor | C11 | | | | 1
| CL21A225KOFNNNG | CL21 Series 0805 2.2uF 16V ±10% Tolerance X5R Multilayer Ceramic Chip Capacitor | C12 | | | | 1
| CL21B104KOANNNC | CL21 Series 0805 100nF 16V ±10% Tolerance X7R Multilayer Ceramic Chip Capacitor | C13 | | | | 1
| CL21B104KOANNNC | CL21 Series 0805 100nF 16V ±10% Tolerance X7R Multilayer Ceramic Chip Capacitor | C14 | | | | 1
| CC1206KKX7R9BB475 | CAP CER 4.7UF 50V X7R 1206 | C15 | | | | 1
| 12065C105KAT2A | General Purpose Ceramic Capacitor, 1206, 1uF, 10%, X7R, 15%, 50V | C16 | | | | 1
| CL21B104KOANNNC | CL21 Series 0805 100nF 16V ±10% Tolerance X7R Multilayer Ceramic Chip Capacitor | C17 | | | | 1
| CL21B104KOANNNC | CL21 Series 0805 100nF 16V ±10% Tolerance X7R Multilayer Ceramic Chip Capacitor | C18 | | | | 1
| CL21B104KOANNNC | CL21 Series 0805 100nF 16V ±10% Tolerance X7R Multilayer Ceramic Chip Capacitor | C19 | | | | 1
| CL21B104KOANNNC | CL21 Series 0805 100nF 16V ±10% Tolerance X7R Multilayer Ceramic Chip Capacitor | C20 | | | | 1
| CL21B104KOANNNC | CL21 Series 0805 100nF 16V ±10% Tolerance X7R Multilayer Ceramic Chip Capacitor | C21 | | | | 1
| CL21B104KOANNNC | CL21 Series 0805 100nF 16V ±10% Tolerance X7R Multilayer Ceramic Chip Capacitor | C22 | | | | 1
| CL21B104KOANNNC | CL21 Series 0805 100nF 16V ±10% Tolerance X7R Multilayer Ceramic Chip Capacitor | C23 | | | | 1
| 1206ZD106KAT2A | General Purpose Ceramic Capacitor, 1206, 10uF, 10%, X5R, 15%, 10V | C24 | | | | 1
| CL21B104KOANNNC | CL21 Series 0805 100nF 16V ±10% Tolerance X7R Multilayer Ceramic Chip Capacitor | C25 | | | | 1
| CL21B104KOANNNC | CL21 Series 0805 100nF 16V ±10% Tolerance X7R Multilayer Ceramic Chip Capacitor | C26 | | | | 1
| CL21B104KOANNNC | CL21 Series 0805 100nF 16V ±10% Tolerance X7R Multilayer Ceramic Chip Capacitor | C27 | | | | 1
| CL21B104KOANNNC | CL21 Series 0805 100nF 16V ±10% Tolerance X7R Multilayer Ceramic Chip Capacitor | C28 | | | | 1
| CL21B104KOANNNC | CL21 Series 0805 100nF 16V ±10% Tolerance X7R Multilayer Ceramic Chip Capacitor | C29 | | | | 1
| CL21B104KOANNNC | CL21 Series 0805 100nF 16V ±10% Tolerance X7R Multilayer Ceramic Chip Capacitor | C30 | | | | 1
| CL21B104KOANNNC | CL21 Series 0805 100nF 16V ±10% Tolerance X7R Multilayer Ceramic Chip Capacitor | C31 | | | | 1
| CL21B104KOANNNC | CL21 Series 0805 100nF 16V ±10% Tolerance X7R Multilayer Ceramic Chip Capacitor | C32 | | | | 1
| CL21B104KOANNNC | CL21 Series 0805 100nF 16V ±10% Tolerance X7R Multilayer Ceramic Chip Capacitor | C33 | | | | 1
| CL21B104KOANNNC | CL21 Series 0805 100nF 16V ±10% Tolerance X7R Multilayer Ceramic Chip Capacitor | C34 | | | | 1
| 1206ZD106KAT2A | General Purpose Ceramic Capacitor, 1206, 10uF, 10%, X5R, 15%, 10V | C35 | | | | 1
| 100nF | Automotive Ceramic Capacitor, 0805, 100nF, 10%, X7R, 15%, 100V | C36 | | | | 1
| CC1206KKX7R9BB475 | CAP CER 4.7UF 50V X7R 1206 | C37 | | | | 1
| C3216X5R1E226M160AB | Multilayer Ceramic Capacitors 22uF ±20% 25V X5R SMD 1206 | C38 | | | | 1
| C3216X5R1E226M160AB | Multilayer Ceramic Capacitors 22uF ±20% 25V X5R SMD 1206 | C39 | | | | 1
| 100nF | Automotive Ceramic Capacitor, 0805, 100nF, 10%, X7R, 15%, 100V | C40 | | | | 1
| 1206ZD106KAT2A | General Purpose Ceramic Capacitor, 1206, 10uF, 10%, X5R, 15%, 10V | C41 | | | | 1
| 12065C105KAT2A | General Purpose Ceramic Capacitor, 1206, 1uF, 10%, X7R, 15%, 50V | C42 | | | | 1
| USBLC6-2SC6Y | 17V Clamp 5A (8/ 20µs) Ipp Tvs Diode Surface Mount SOT-23-6 | D1 | | | | 1
| 694106301002 HSMG-C170 | Chip LED, Green, 2.2 V, -40 to 85 degC, 2-Pin SMD, Pb-Free, Tape and Reel | DC-Jack1 DS1 | | | | 1 1
HSMG-C170 | Chip LED, Green, 2.2 V, -40 to 85 degC, 2-Pin SMD, Pb-Free, Tape and Reel | DS2 | 1
105017-0001 | Micro-USB B Receptacle, Right Angle, Bottom Mount, Surface Mount, with Solder Tabs, -30 to 85 degC, 5-Pin USB, RoHS, Tape and Reel | J1 | 1
B8B-XH-A(LF)(SN) | Connector Header Through Hole 8 position 0.098 (2.50mm) | J2 | 1
B8B-XH-A(LF)(SN) | Connector Header Through Hole 8 position 0.098 (2.50mm) | J3 | 1
B8B-XH-A(LF)(SN) | Connector Header Through Hole 8 position 0.098 (2.50mm) | J4 | 1
SONAR1 | Connector Header Through Hole 4 position 0.098 (2.50mm) | J5 | 1
SONAR2 | Connector Header Through Hole 4 position 0.098 (2.50mm) | J6 | 1
SPEAKER | Connector Header Through Hole 5 position 0.098 (2.50mm) | J7 | 1
SONAR3 | Connector Header Through Hole 4 position 0.098 (2.50mm) | J8 | 1
B8B-XH-A(LF)(SN) | Connector Header Through Hole 8 position 0.098 (2.50mm) | J9 | 1
B2B-XH-A(LF)(SN) | Connector Header Through Hole 2 position 0.098 (2.50mm) | J10 | 1
UART INTERFACE | Connector Header Through Hole 4 position 0.100 (2.54mm) | J11 | 1
MTLW-104-06-G-D-160 | | J12 | 1
MTLW-102-XX-X-D-XXX | Connector Header Through Hole 4 position 0.100 (2.54mm) | J13 | 1
IHLP2525BDER4R7M01 | Commercial Inductors, High Saturation Series 4.7uH 4.5A 63mΩ 20% | L1 | 1
61204022021 RC0805JR-0710KL | Chip Resistor, 10 KOhm, +/- 5%, 0.125 W, -55 to 155 degC, 0805 (2012 Metric), RoHS, Tape and Reel | P1 R1 | 1 1
RC0805JR-0710KL | Chip Resistor, 10 KOhm, +/- 5%, 0.125 W, -55 to 155 degC, 0805 (2012 Metric), RoHS, Tape and Reel | R2 | 1
RC0805JR-0710KL | Chip Resistor, 10 KOhm, +/- 5%, 0.125 W, -55 to 155 degC, 0805 (2012 Metric), RoHS, Tape and Reel | R3 | 1
RC0805JR-0710KL | Chip Resistor, 10 KOhm, +/- 5%, 0.125 W, -55 to 155 degC, 0805 (2012 Metric), RoHS, Tape and Reel | R4 | 1
RC0805JR-0710KL | Chip Resistor, 10 KOhm, +/- 5%, 0.125 W, -55 to 155 degC, 0805 (2012 Metric), RoHS, Tape and Reel | R5 | 1
RC0805JR-0710KL | Chip Resistor, 10 KOhm, +/- 5%, 0.125 W, -55 to 155 degC, 0805 (2012 Metric), RoHS, Tape and Reel | R6 | 1
RC0805JR-0710KL | Chip Resistor, 10 KOhm, +/- 5%, 0.125 W, -55 to 155 degC, 0805 (2012 Metric), RoHS, Tape and Reel | R7 | 1
RC0805JR-0710KL | Chip Resistor, 10 KOhm, +/- 5%, 0.125 W, -55 to 155 degC, 0805 (2012 Metric), RoHS, Tape and Reel | R8 | 1

Line # | Comment | Description | Designator | Revision ID | Revision Status | Quantity | Manufacturer 1 | Manufacturer Part Number 1 | Manufacturer Lifecycle 1 | Supplier 1 | Supplier Part Number 1 | Supplier Unit Price 1 | Supplier Subtotal 1
RC0805JR-0710KL | Chip Resistor, 10 KOhm, +/- 5%, 0.125 W, -55 to 155 degC, 0805 (2012 Metric), RoHS, Tape and Reel | R9 | 1
RC0805JR-0710KL | Chip Resistor, 10 KOhm, +/- 5%, 0.125 W, -55 to 155 degC, 0805 (2012 Metric), RoHS, Tape and Reel | R10 | 1
RC0805JR-0710KL | Chip Resistor, 10 KOhm, +/- 5%, 0.125 W, -55 to 155 degC, 0805 (2012 Metric), RoHS, Tape and Reel | R11 | 1
RC0805JR-0710KL | Chip Resistor, 10 KOhm, +/- 5%, 0.125 W, -55 to 155 degC, 0805 (2012 Metric), RoHS, Tape and Reel | R12 | 1
RC0805JR-0710KL | Chip Resistor, 10 KOhm, +/- 5%, 0.125 W, -55 to 155 degC, 0805 (2012 Metric), RoHS, Tape and Reel | R13 | 1
RC0805JR-0710KL | Chip Resistor, 10 KOhm, +/- 5%, 0.125 W, -55 to 155 degC, 0805 (2012 Metric), RoHS, Tape and Reel | R14 | 1
RC0805JR-0710KL | Chip Resistor, 10 KOhm, +/- 5%, 0.125 W, -55 to 155 degC, 0805 (2012 Metric), RoHS, Tape and Reel | R15 | 1
CG0603MLC-05E | ESD Protector, 5 V Supply, -40 to 85 degC, 1.6 x 0.8 x 0.55 mm SMD, RoHS, Tape and Reel | RV1 | 1
SWITCH | SWITCH TACTILE SPST-NO 0.05A 12V | SW1 | 1
SWITCH | SWITCH TACTILE SPST-NO 0.05A 12V | SW2 | 1
5000 | Test Point Miniature THM H .300 Nylon 46 Insulated Red PhosBronze/Silver | Keystone Electronics 5000 | TP1 | 1
5000 | Test Point Miniature THM H .300 Nylon 46 Insulated Red PhosBronze/Silver | Keystone Electronics 5000 | TP2 | 1
5000 | Test Point Miniature THM H .300 Nylon 46 Insulated Red PhosBronze/Silver | Keystone Electronics 5000 | TP3 | 1
ATSAM3X8EA-AU | SAM3X ARM Cortex-M3 Flash-based Microcontroller, 512 KB Flash, 96 KB SRAM, 103 User I/ Os, 1.62 to 3.6 V, -40 to 85 degC, 144-Pin LQFP, RoHS | U1 | 1
LDL1117S33R | IC REG LINEAR 3.3V 1.2A SOT223 | U2 | 1
W25Q128FVSIG | 3V 128M-Bit Serial Flash Memory with Dual/Quad SPI & QPI, 2.7 to 3.6 V, -40 to 85 degC, 8-Pin SOIC, RoHS, Tape and Reel | U3 | 1
SN74LVC2T45DCTR | IC TRNSLTR BIDIRECTIONAL SM8 | U4 | 1
SN74LVC2T45DCTR | IC TRNSLTR BIDIRECTIONAL SM8 | U5 | 1
SN74LVC2T45DCTR | IC TRNSLTR BIDIRECTIONAL SM8 | U6 | 1
SN74LVC2T45DCTR | IC TRNSLTR BIDIRECTIONAL SM8 | U7 | 1
AP63205WU-7 | IC REG BUCK 5V 2A TSOT26 | U8 | 1
LDL1117S33R | IC REG LINEAR 3.3V 1.2A SOT223 | U9 | 1
12MHZ | Crystal 12MHz ±20ppm (Tol) ±30ppm (Stability) 18pF FUND 120Ω 4-Pin SMD T/R | Y1 | 1
32.768KHZ | NX3215SA-32.768K-STD-MUA-14 Parallel -Fundamental Quartz Crystal, 0.032768MHz Nom | Y2 | 1

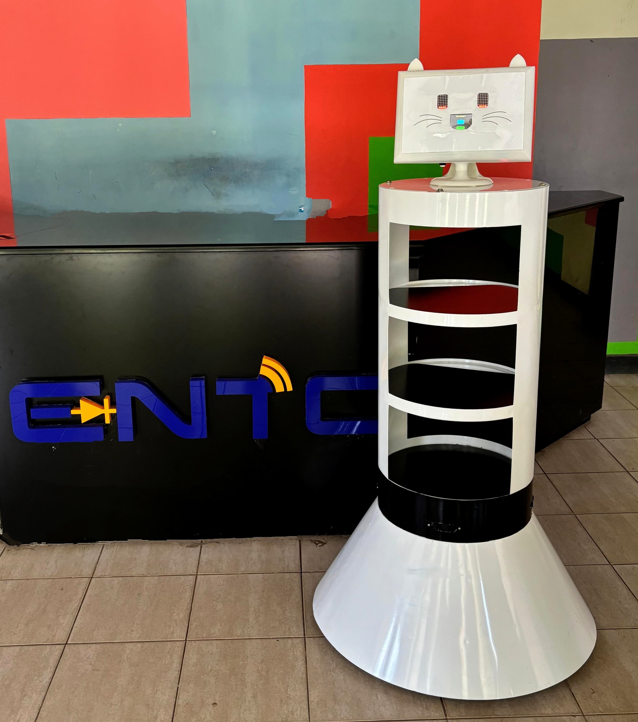
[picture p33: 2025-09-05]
Images/Front1.jpg

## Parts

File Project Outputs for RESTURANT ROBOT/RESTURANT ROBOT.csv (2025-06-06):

Line # | Name | Description | Designator | Revision ID | Revision Status | Quantity | Manufacturer 1 | Manufacturer Part Number 1 | Manufacturer Lifecycle 1 | Supplier 1 | Supplier Part Number 1 | Supplier Unit Price 1 | Supplier Subtotal 1
 | CL21B104KOANNNC | CL21 Series 0805 100nF 16V ±10% Tolerance X7R Multilayer Ceramic Chip Capacitor | C1, C2, C8, C9, C10, C11, C13, C14, C17, C18, C19, C20, C21, C22, C23, C25, C26, C27, C28, C29, C30, C31, C32, C33, C34 |  |  | 25 | Samsung | CL21B104KOANNNC | Volume Production
 | C0805C120J5GACTU | CAP CER 12PF 50V C0G/NP0 0805 | C3, C4, C5, C6 |  |  | 4 | KEMET | C0805C120J5GACTU | Volume Production | Digikey | 399-C0805C120J5GACTUCT-ND | 0.11 | 0.44
 | CL21A225KOFNNNG | CL21 Series 0805 2.2uF 16V ±10% Tolerance X5R Multilayer Ceramic Chip Capacitor | C7, C12 |  |  | 2 | Samsung | CL21A225KOFNNNG | Volume Production
 | CC1206KKX7R9BB475 | CAP CER 4.7UF 50V X7R 1206 | C15, C37 |  |  | 2 | Yageo | CC1206KKX7R9BB475 | Volume Production | Arrow Electronics | CC1206KKX7R9BB475 | 0.4124 | 0.8248
 | 12065C105KAT2A | General Purpose Ceramic Capacitor, 1206, 1uF, 10%, X7R, 15%, 50V | C16, C42 |  |  | 2 | Kyocera AVX | 12065C105KAT2A | Volume Production | Newark | 10R6014 | 0.096 | 0.192
 | 1206ZD106KAT2A | General Purpose Ceramic Capacitor, 1206, 10uF, 10%, X5R, 15%, 10V | C24, C35, C41 |  |  | 3 | Kyocera AVX | 1206ZD106KAT2A | Volume Production | Farnell | 1327730 | 0.3193 | 1.6
 | 100nF | Automotive Ceramic Capacitor, 0805, 100nF, 10%, X7R, 15%, 100V | C36, C40 |  |  | 2 | Kyocera AVX | 08051C104K4T2A | Volume Production | Digikey | 478-KAM21KR72A104KUCT-ND | 0.28 | 0.56
 | C3216X5R1E226M160AB | Multilayer Ceramic Capacitors 22uF ±20% 25V X5R SMD 1206 | C38, C39 |  |  | 2 | TDK | C3216X5R1E226M160AB | Volume Production | Newark | 04X3296 | 0.4 | 0.8
 | USBLC6-2SC6Y | 17V Clamp 5A (8/20µs) Ipp Tvs Diode Surface Mount SOT-23-6 | D1 |  |  | 1
 | 694106301002 |  | DC-Jack1 |  |  | 1 | Wurth Electronics | 694106301002 | Volume Production | Digikey | 732-5930-ND | 0.92 | 0.92
 | HSMG-C170 | Chip LED, Green, 2.2 V, -40 to 85 degC, 2-Pin SMD, Pb-Free, Tape and Reel | DS1, DS2 |  |  | 2 | Broadcom Avago | HSMG-C170 | Volume Production | Mouser | 630-HSMG-C170 | 0.28 | 0.56
 | 105017-0001 | Micro-USB B Receptacle, Right Angle, Bottom Mount, Surface Mount, with Solder Tabs, -30 to 85 degC, 5-Pin USB, RoHS, Tape and Reel | J1 |  |  | 1 | Molex | 1050170001 | Volume Production | Arrow Electronics | 1050170001 | 0.3241 | 0.3241
 | B8B-XH-A(LF)(SN) | Connector Header Through Hole 8 position 0.098 (2.50mm) | J2, J3, J4, J9 |  |  | 4
 | SONAR1 | Connector Header Through Hole 4 position 0.098 (2.50mm) | J5 |  |  | 1
 | SONAR2 | Connector Header Through Hole 4 position 0.098 (2.50mm) | J6 |  |  | 1
 | SPEAKER | Connector Header Through Hole 5 position 0.098 (2.50mm) | J7 |  |  | 1
 | SONAR3 | Connector Header Through Hole 4 position 0.098 (2.50mm) | J8 |  |  | 1
 | B2B-XH-A(LF)(SN) | Connector Header Through Hole 2 position 0.098 (2.50mm) | J10 |  |  | 1
 | MTLW-102-XX-X-D-XXX | Connector Header Through Hole 4 position 0.100 (2.54mm) | J11 |  |  | 1
 | MTLW-104-06-G-D-160 |  | J12 |  |  | 1
 | MTLW-102-XX-X-D-XXX | Connector Header Through Hole 4 position 0.100 (2.54mm) | J13 |  |  | 1
 | IHLP2525BDER4R7M01 | Commercial Inductors, High Saturation Series 4.7uH 4.5A 63mO 20% | L1 |  |  | 1 | Vishay Dale | IHLP2525BDER4R7M01 | Volume Production | Newark | 55M4308 | 0.231 | 0.231
 | 61204022021 |  | P1 |  |  | 1 | Wurth Electronics | 61204022021 | Volume Production | Digikey | 732-5420-ND | 2.79 | 2.79
 | RC0805JR-0710KL | Chip Resistor, 10 KOhm, +/- 5%, 0.125 W, -55 to 155 degC, 0805 (2012 Metric), RoHS, Tape and Reel | R1, R2, R3, R4, R5, R6, R7, R8, R9, R10, R11, R12, R13, R14, R15 |  |  | 15 | Yageo | RC0805JR-0710KL | Volume Production | Digikey | 311-10KARCT-ND | 0.012 | 0.18
 | CG0603MLC-05E | ESD Protector, 5 V Supply, -40 to 85 degC, 1.6 x 0.8 x 0.55 mm SMD, RoHS, Tape and Reel | RV1 |  |  | 1 | Bourns | CG0603MLC-05E | Not Recommended for New Design | Mouser | 652-CG0603MLC-05E | 0.25 | 0.25
 | SWITCH | SWITCH TACTILE SPST-NO 0.05A 12V | SW1, SW2 |  |  | 2
 | 5000 | Test Point Miniature THM H .300 Nylon 46 Insulated Red PhosBronze/Silver | Keystone Electronics 5000 | TP1, TP2, TP3, TP4, TP5 |  |  | 5
 | ATSAM3X8EA-AU | SAM3X ARM Cortex-M3 Flash-based Microcontroller, 512 KB Flash, 96 KB SRAM, 103 User I/Os, 1.62 to 3.6 V, -40 to 85 degC, 144-Pin LQFP, RoHS | U1 |  |  | 1 | Microchip | ATSAM3X8EA-AU | Volume Production | Mouser | 556-ATSAM3X8EA-AU | 13.15 | 13.15
 | LDL1117S33R | IC REG LINEAR 3.3V 1.2A SOT223 | U2, U9 |  |  | 2 | STMicroelectronics | LDL1117S33R | Volume Production | Newark | 14AC6965 | 0.115 | 0.23
 | W25Q128FVSIG | 3V 128M-Bit Serial Flash Memory with Dual/Quad SPI & QPI, 2.7 to 3.6 V, -40 to 85 degC, 8-Pin SOIC, RoHS, Tape and Reel | U3 |  |  | 1 | Winbond | W25Q128FVSIG | Obsolete
 | SN74LVC2T45DCTR | IC TRNSLTR BIDIRECTIONAL SM8 | U4, U5, U6, U7 |  |  | 4 | Texas Instruments | SN74LVC2T45DCTR | Volume Production | Mouser | 595-SN74LVC2T45DCTR | 0.38 | 1.52
 | AP63205WU-7 | IC REG BUCK 5V 2A TSOT26 | U8 |  |  | 1 | Diodes | AP63205WU-7 | Volume Production | Mouser | 621-AP63205WU-7 | 1.38 | 1.38
 | 12MHZ | Crystal 12MHz ±20ppm (Tol) ±30ppm (Stability) 18pF FUND 120? 4-Pin SMD T/R | Y1 |  |  | 1 | Abracon | ABM8G-12.000MHZ-18-D2Y-T |  | Farnell | 2308709 | 0.40178 | 0.40178
 | 32.768KHZ | NX3215SA-32.768K-STD-MUA-14 Parallel - Fundamental Quartz Crystal, 0.032768MHz Nom | Y2 |  |  | 1 | NDK | NX3215SA-32.768K-STD-MUA-14 | Volume Production | Mouser | 344-NX3215SA32768K14 | 0.68 | 0.68

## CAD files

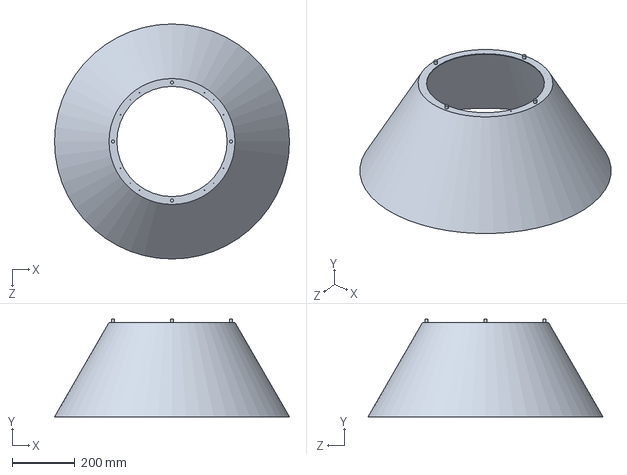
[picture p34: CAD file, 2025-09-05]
Solidworks/Bottomhousing^FULL_ASSEMBLY.SLDPRT
746.4 x 310.0 x 746.4 mm

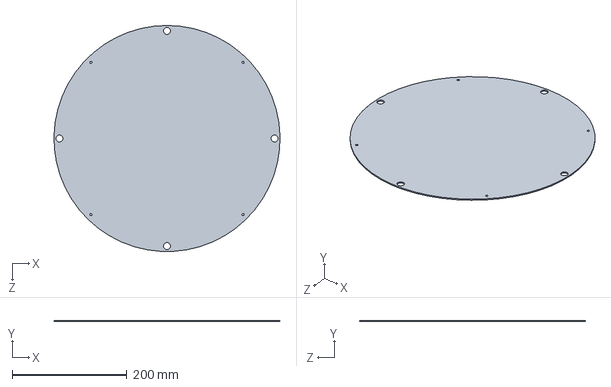
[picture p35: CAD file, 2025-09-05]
Solidworks/Coverplate.SLDPRT
393.8 x 2.00 x 394.0 mm

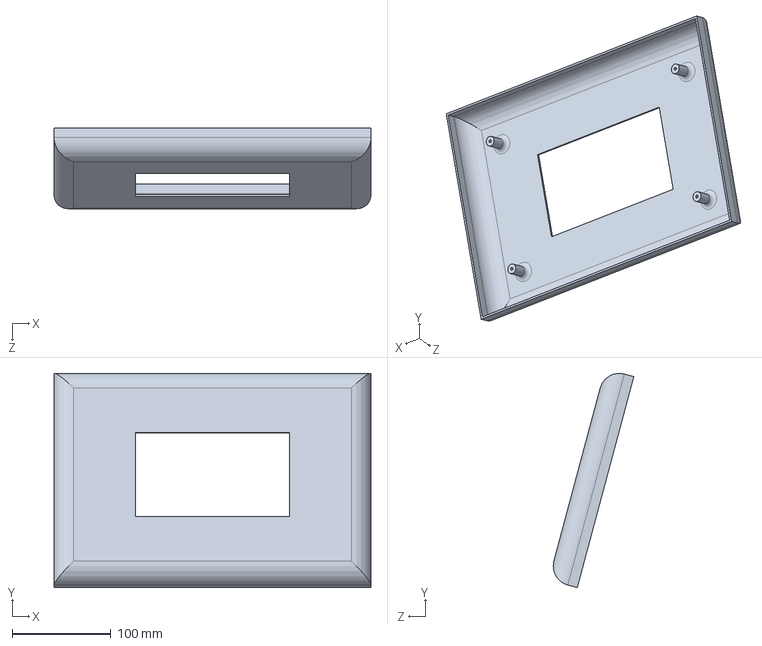
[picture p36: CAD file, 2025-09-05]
Solidworks/displaycase_lid.SLDPRT
321.4 x 217.2 x 81.8 mm

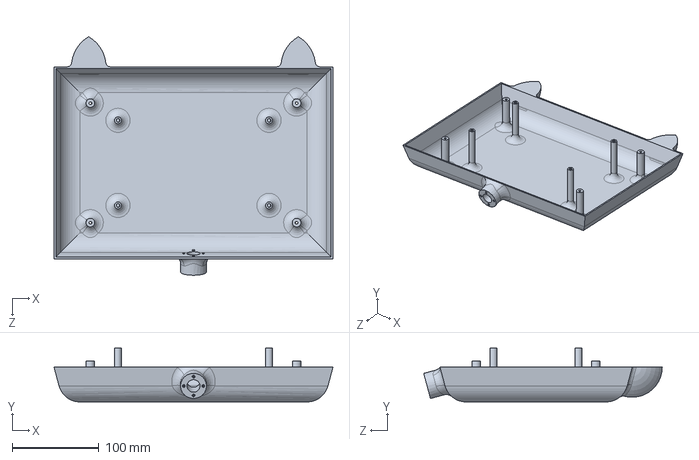
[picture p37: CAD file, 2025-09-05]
Solidworks/back.SLDPRT
321.4 x 62.0 x 274.9 mm

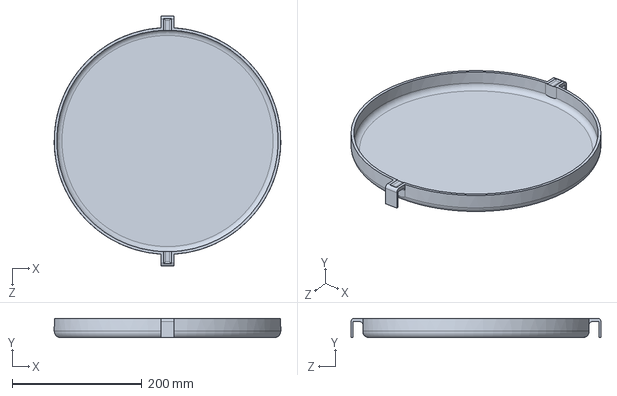
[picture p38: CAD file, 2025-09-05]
Solidworks/origianl tray.SLDPRT
349.9 x 30.0 x 386.0 mm

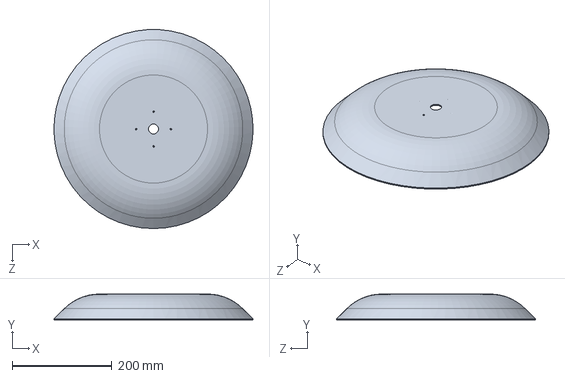
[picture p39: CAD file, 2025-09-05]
Solidworks/base.SLDPRT
399.8 x 52.0 x 400.0 mm

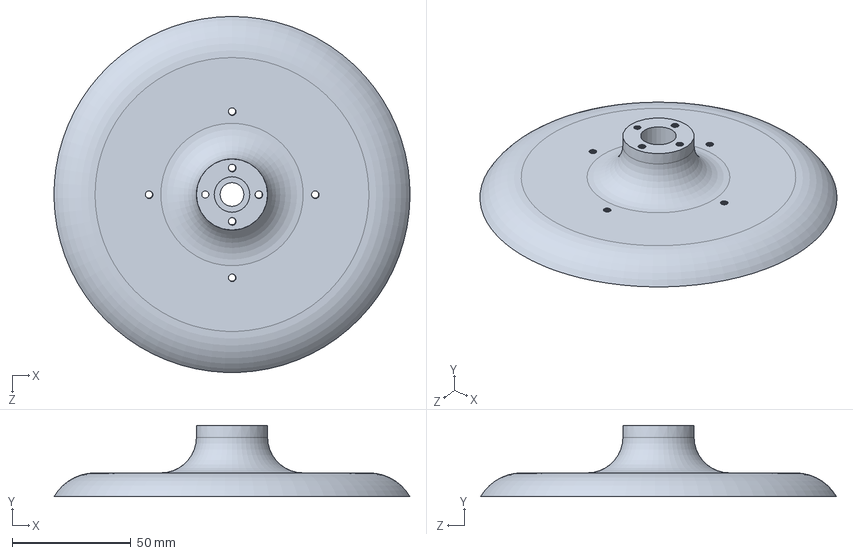
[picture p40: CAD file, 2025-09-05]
Solidworks/stand.SLDPRT
150.0 x 30.0 x 150.0 mm

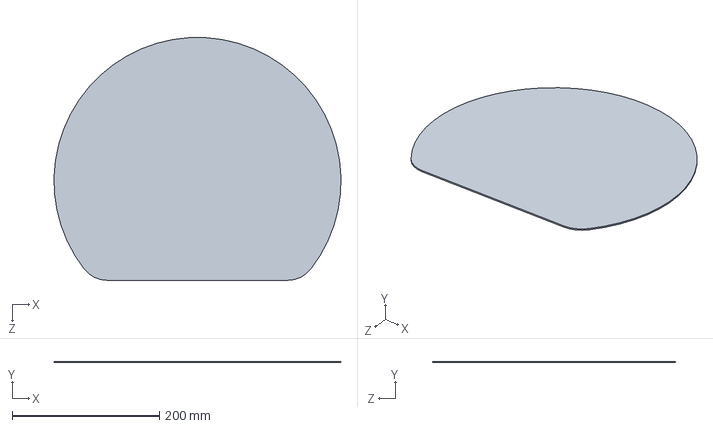
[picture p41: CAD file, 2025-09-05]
Solidworks/newtray.SLDPRT
389.9 x 2.00 x 329.7 mm

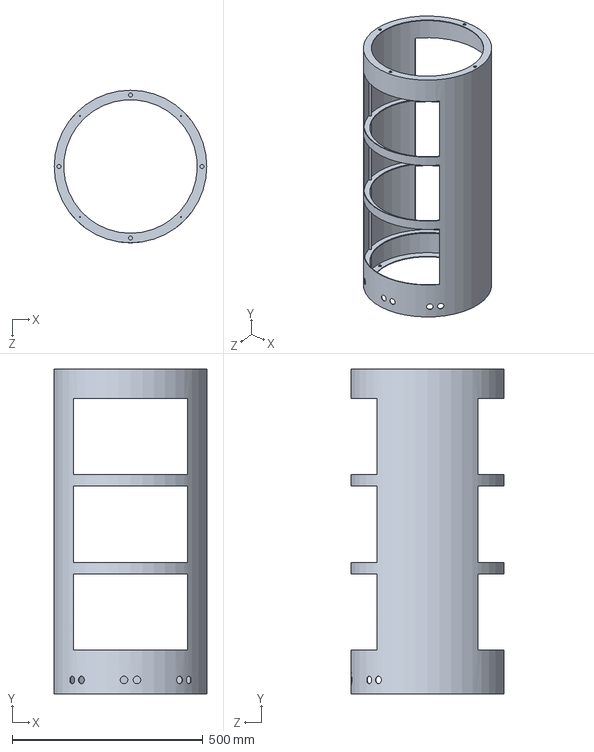
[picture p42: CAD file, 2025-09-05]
Solidworks/outer_frame.SLDPRT
400.0 x 852.0 x 400.0 mm

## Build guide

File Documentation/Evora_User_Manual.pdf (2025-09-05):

# R E S T A U R A N T S E R V I C E

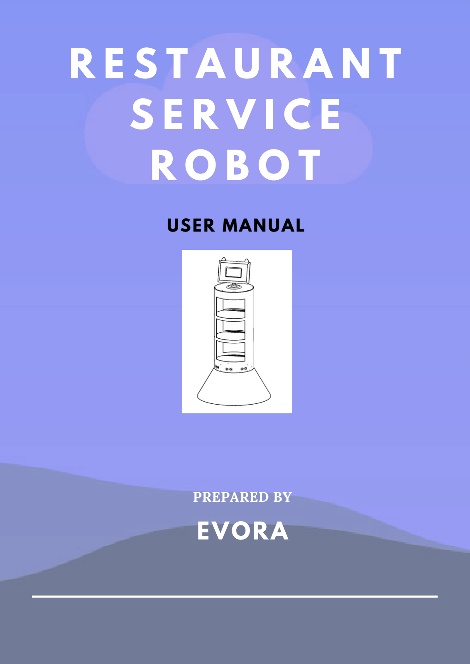
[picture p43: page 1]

# R O B O T

## USER MANUAL

# EVORA

## PREPARED BY

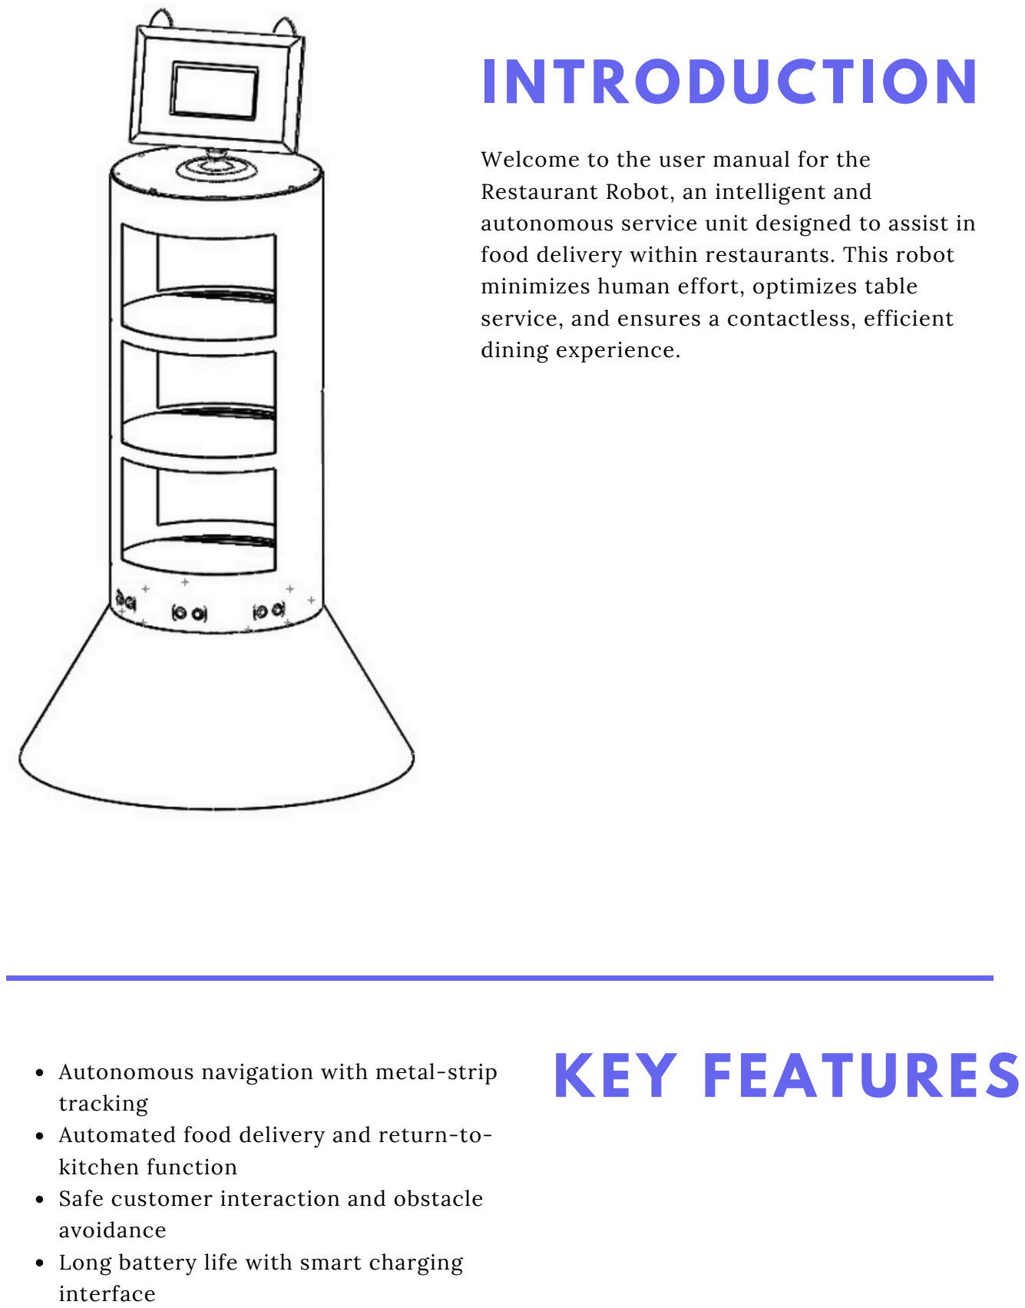
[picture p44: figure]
INTRODUCTION; Welcome to the user manual for the Restaurant Robot, an intelligent and; minimizes human effort, optimizes table; dining experience.; KEY FEATURES; Autonomous navigation with metal-strip tracking Automated food delivery and return-to- kitchen function Safe customer interaction and obstacle avoidance Long battery life with smart charging interface

autonomous service unit designed to assist in food delivery within restaurants. This robot

service, and ensures a contactless, efficient

Parameter | Specification
Operating Voltage | 24V
Charging Time | 30min
Battery Lifetime | 30min
Cruise Speed | 0.1ms⁻¹
Number of Trays | 3
Tray Load | 5kg
Material | Stainless Steal
Battery Capacity | 6200mAh
Weight | 50kg
Dimensions(LxWxH) | 80cmx80cmx145cm

## Food Delivery Mode – Step-by-Step Process

In delivery mode, the robot is capable of serving multiple tables in a single run. Food for different customers is placed on separate trays, and the robot plans the most efficient path to deliver them sequentially. Once deliveries are complete, it automatically returns to the food pick-up point.

### 1. Dish Loading

The waiter places the food items on the trays, assigning different trays to different orders if necessary.

### 2. Mode and Table Selection

On the touchscreen, the waiter selects Delivery Mode. Then, they tap the tray icon and assign a table number for each one. The robot registers and maps out the route accordingly.

### 3. Task Start

Once all table numbers are entered, the waiter presses Start. The robot begins navigating autonomously.

### 4. Navigation

It follows a predefined path using metal strips on the floor:
Single metal strip: Normal navigation path
Double metal strip: Indicates junctions to detect turns and table locations

### 5. Arrival & Positioning

Upon reaching the assigned table, the robot:
Rotates to face the customer directly
Announces arrival with a voice prompt
Displays a message on the screen inviting the customer to retrieve their food

### 6. Food Pickup by Customer

Customers take their food. They may tap the screen to confirm completion, or the robot resumes automatically after a brief pause.

### 7. Return to Kitchen

Once all deliveries are completed, the robot returns to the starting position and waits for the next task.
After the customer touches the “Return” button on the screen, the robot navigates back to the kitchen area autonomously.

# WORKING MECHANISM

## Power ON, Power OFF, Pause, and Start Instructions

Before Each Power-On: Position the robot directly under the visual mark for accurate initialization.
Power-On: Hold the power button for 0.5 seconds. A blue light will appear at the base. Startup: The touchscreen will enter working mode to indicate successful boot. Power-Off: Press and hold the power button for 3 seconds to shut down. For a forced shutdown, hold for 10 seconds (only if the robot is unresponsive).

## Charging Instructions

To begin charging:
Connect the robot’s charging port to the provided charger.
Ensure a secure connection. A charging prompt will appear on the robot’s screen when connected successfully.

## Power Requirements

1.Keep battery level above 10% during operation to ensure optimal battery health.
2.When the battery falls below 10%, the robot enters low-power mode and should be charged promptly.
3.If the battery level drops below 2%, the robot will stop all functions to protect the battery and must be recharged before use.

Battery Type: Lithium-Ion
Charging Port: DC Input (use only original adapter)
Battery Status: Displayed via screen and front LED
Low Power Warning: Robot returns to charge when battery < 20%

# POWER & CHARGING

## Power and Charging Requirements

1.Charge the robot when battery drops below 20% to avoid long-term battery degradation.
2.Always ensure the battery is properly installed before connecting the charger.
3. Do not remove the detachable battery while charging.
4.Never remove the battery while the robot is powered on.
5.Once fully charged, disconnect the power to avoid overcharging.
6.If not used for an extended period, switch off and lock the robot to protect the battery.
7.Only use manufacturer-provided battery and charging accessories.
8.Confirm the voltage input matches the rating on the charger label.
9.Only use the original charger for the detachable battery; battery charge level is shown via indicator lights.
10.Ensure the robot is powered off before swapping batteries.
11.Using incorrect voltage may damage the charger; always verify compatibility. 12.Handle charging cables gently—avoid pulling or twisting them.
13.Assign a responsible person to oversee charging. Do not leave the robot charging unattended.
14. Do not charge near flammable or explosive items.
15.Always store and charge in a dry, cool area (below 40°C). Keep water away. 16.Prevent the charger from any physical damage or strong impacts.
17.Replace the charger immediately if damaged or showing irregular current. 18.If the robot shows a charging-related error, disconnect the power immediately.

Note: Avoid leaving the robot charging unattended overnight. Ensure a dry and ventilated charging area.

# POWER & CHARGING

1.Never exceed the maximum load: 10kg per tray (standard) or 5kg per tray (when covered).
2.Always press the "Finish" button only after customers have collected their food to start the next task.

### 3. Do not pick up or place food while the robot is moving. Use the screen to pause

the robot first. Note: pause duration is 20 seconds in cruise mode and 10 seconds in other modes.
4. Do not press forcefully or tap aggressively on the touchscreen.
5.Never pull the robot manually during its operation.
6.Avoid pushing the robot backward while it is powered on.
7.If the robot deviates from its route due to obstacles, pause it and gently guide it back to the correct path before resuming.
8.In case of a collision, pause or cancel the task. Do not try to force or block the robot.
9.Unless using a special tray, avoid delivering soups. If used, ensure containers are sealed to prevent burns or spillage.
10.Keep a safe distance when the robot is transporting hot items to avoid collisions or burns.
11.The top camera is essential for navigation. Do not obstruct it with any covering.
12.Avoid hitting, shaking, or interacting roughly with the robot, as this may damage its components.
13.Children must interact under adult supervision.
14. Do not place or charge the robot near flammable or explosive materials. 15.Ensure the robot is stored and charged in a dry, temperature-controlled environment (below 40°C). Prevent water or moisture from entering the machine or charger.
16.Protect the charger from collisions or external damage.
17.Replace the charger if it shows signs of damage or abnormal charging current. 18.Immediately disconnect the charging power source if a robot error or alarm is triggered.
19.Pause the robot before pushing or relocating it.
20.Never pour liquids into any part of the robot.
21. Do not place objects, children, or pets on the robot at any time.
22.Although equipped with obstacle avoidance, never intentionally block the robot during fast movement to avoid accidents.
23.Be aware of the robot's blind-spot detection limitations and avoid interfering within its low-ground detection zone.

# SAFETY INSTRUCTIONS

### Trays, Drive Wheels, and Auxiliary Wheels

Clean the trays regularly using a soft cotton cloth.
Inspect and clean the drive and auxiliary wheels weekly.
If debris is stuck in the wheels, gently lift the robot to remove it safely.

### Sensor Maintenance

Clean the top-positioning sensor and 3D obstacle-avoidance sensors weekly. If contaminated, clean immediately using lens-safe tissue or cloth. Obstructed sensors may cause abnormal movement or positioning errors.

Robot Body Maintenance
Wipe the robot’s surface with a dry or lightly damp cotton cloth.
Never lift, bump, climb on, or apply force to the robot.
Do not stack any objects on the robot.
Do not disassemble any part of the robot unless instructed by a certified technician.

### Handling the Robot

During transport, use proper equipment (e.g., forklifts) that meets GB/T 4857.23-2012 standards.
If manually moved, lift the robot from both sides (as marked) using two people. Maintain balance and keep the robot upright. Never lift by holding the tray.

### Sign Maintenance

Do not hang any items (balloons, banners, etc.) directly under or near the ceiling signs.
Avoid damaging or repositioning the signs during ceiling maintenance.

# PRODUCT MAINTENANCE

### For technical support or warranty service, contact:

Email: msboralu@gmail.com
Phone: +94 712543035

Thank you for choosing the Restaurant Robot. For questions, support, or training, don’t hesitate to reach out!

# CONTACT & SUPPORT

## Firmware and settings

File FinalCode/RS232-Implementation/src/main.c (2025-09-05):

#include <asf.h>

// Onboard LED pin definitions (PB27)
#define LED_PIO        PIOB
#define LED_PIN_MASK   PIO_PB27
#define LED_PIN_ID     ID_PIOB

// LED for 'B' ? Pin 46 = PC17
#define LEDB_PIO        PIOC
#define LEDB_PIN_MASK   (1u << 17)
#define LEDB_PIN_ID     ID_PIOC

// LED for 'C' ? Pin 48 = PC15
#define LEDC_PIO        PIOC
#define LEDC_PIN_MASK   (1u << 15)
#define LEDC_PIN_ID     ID_PIOC

// USART0 pin definitions (TX1 = PA11, RX1 = PA10)
#define UART_PIO       PIOA
#define UART_ID        ID_USART0
#define UART_RX_PIN    PIO_PA10A_RXD0
#define UART_TX_PIN    PIO_PA11A_TXD0
#define UART_PERIPHERAL USART0

void blink_led(Pio *pio, uint32_t pin_mask) {
	pio_set(pio, pin_mask);
	delay_ms(100);
	pio_clear(pio, pin_mask);
}

int main(void)
{
	// Initialize system clock and delay
	sysclk_init();
	delay_init(sysclk_get_cpu_hz());

	// Enable peripheral clocks
	pmc_enable_periph_clk(UART_ID);      // USART0
	pmc_enable_periph_clk(ID_PIOA);      // PIOA for UART
	pmc_enable_periph_clk(LED_PIN_ID);   // PIOB for LED
	pmc_enable_periph_clk(LEDB_PIN_ID);   // PC13
	pmc_enable_periph_clk(LEDC_PIN_ID);   // PC15

	// Configure USART0 RX/TX pins (Peripheral A)
	pio_configure(UART_PIO, PIO_PERIPH_A, UART_RX_PIN | UART_TX_PIN, PIO_DEFAULT);

	// Configure USART0 options
	sam_usart_opt_t usart_settings = {
		.baudrate     = 9600,
		.char_length  = US_MR_CHRL_8_BIT,
		.parity_type  = US_MR_PAR_NO,
		.stop_bits    = US_MR_NBSTOP_1_BIT,
		.channel_mode = US_MR_CHMODE_NORMAL
	};

	// Initialize USART0 with peripheral clock
	usart_init_rs232(UART_PERIPHERAL, &usart_settings, sysclk_get_peripheral_hz());

	// Enable RX and TX
	usart_enable_tx(UART_PERIPHERAL);
	usart_enable_rx(UART_PERIPHERAL);

	// Configure on board LED as output
	pio_set_output(LED_PIO, LED_PIN_MASK, LOW, DISABLE, ENABLE);
	pio_set_output(LEDB_PIO, LEDB_PIN_MASK, LOW, DISABLE, ENABLE); // D46
	pio_set_output(LEDC_PIO, LEDC_PIN_MASK, LOW, DISABLE, ENABLE);

	// Main loop
	while (1) {
		uint32_t received_char;
		if (usart_read(UART_PERIPHERAL, &received_char) == 0) {
			switch ((char)received_char) {
				case '1':
				blink_led(LED_PIO, LED_PIN_MASK);
				break;
				case '2':
				blink_led(LEDB_PIO, LEDB_PIN_MASK);
				break;
				case '3':
				blink_led(LEDC_PIO, LEDC_PIN_MASK);
				break;
			}
		}
	}
}

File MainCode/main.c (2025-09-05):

#include <asf.h>
#include <math.h>
#include "sam3xa.h"
#include "system_sam3x.h"
#include <stdint.h>
#include <stdbool.h>

#include <motor.h>
#include <SensorArray.h>
#include <PID.h>
#include <Ultrasonic.h>
#include <Scurve.h>

		"""Following Pins used for testing purposes """
// Onboard LED pin definitions (PB27)
#define LED_PIO        PIOB
#define LED_PIN_MASK   PIO_PB27
#define LED_PIN_ID     ID_PIOB

// LED for '2' → Pin 46 = PC17
#define LEDB_PIO        PIOC
#define LEDB_PIN_MASK   (1u << 17)
#define LEDB_PIN_ID     ID_PIOC

// LED for '3' → Pin 48 = PC15
#define LEDC_PIO        PIOC
#define LEDC_PIN_MASK   (1u << 15)
#define LEDC_PIN_ID     ID_PIOC

// USART1 pin definitions (TX = PA13, RX = PA12) → Peripheral A
#define UART_PIO         PIOB
#define UART_ID          ID_USART2
#define UART_RX_PIN      PIO_PB21
#define UART_TX_PIN      PIO_PB20
#define UART_PERIPHERAL  USART2



//other
int temp_2=0;
int temp=0;
int Velocity;
int Table=0;
int Return=0;
int x=1;
int Temp=0;

void table_acceleration(void);
void table_acceleration_2(void);

void leftTurn(void);
void rightTurn(void);
void table_acceleration_return_2(void);
void table_acceleration_return(void);

void communicate(void);
void blink_led(Pio *pio, uint32_t pin_mask);

int main(void) {
	// Initialize the SAM system
 	sysclk_init();
 	board_init();
 	SystemInit();
 	SystemCoreClockUpdate();
 	init_systick();
 	init_ultrasonic();

	//Enable the PIOA peripherals
	PMC->PMC_PCER0 = (1<<11);
	PMC->PMC_PCER0 = (1<<12);
	PMC->PMC_PCER0 = (1<<13);

	//Enable the clock for PIOC (Peripheral I/O Controller B)
	PMC->PMC_PCER0 |= (1 << ID_PIOC);
	
	enablePWMPeripheral();
	enableSensorArray();
	
 	// left motor
	PIOC->PIO_OER |= (1<<7);     // Enable Output
	PIOC->PIO_PER |= (1<<7);     // Enable PIO control
	PIOC->PIO_SODR = (1<<7);  

	// right motor
	PIOC->PIO_OER |= (1<<6);     // Enable Output
	PIOC->PIO_PER |= (1<<6);     // Enable PIO control
	PIOC->PIO_CODR = (1<<6);  

	PIOC->PIO_OER |= (1<<17);     // Enable Output
	PIOC->PIO_PER |= (1<<17);     // Enable PIO control
	
	//communication
	// Initialize system clock and delay
	sysclk_init();
	delay_init(sysclk_get_cpu_hz());

	// Enable peripheral clocks
	pmc_enable_periph_clk(UART_ID);         // USART1
	pmc_enable_periph_clk(ID_PIOA);         // PIOA for UART1 pins
	pmc_enable_periph_clk(LED_PIN_ID);      // PIOB for onboard LED
	pmc_enable_periph_clk(LEDB_PIN_ID);     // PIOC for LEDB
	pmc_enable_periph_clk(LEDC_PIN_ID);     // PIOC for LEDC

	// Configure USART1 RX/TX pins (Peripheral A)
	pio_configure(UART_PIO, PIO_PERIPH_B, UART_RX_PIN | UART_TX_PIN, PIO_DEFAULT);

	// Configure USART1 options
	sam_usart_opt_t usart_settings = {
		.baudrate     = 9600,
		.char_length  = US_MR_CHRL_8_BIT,
		.parity_type  = US_MR_PAR_NO,
		.stop_bits    = US_MR_NBSTOP_1_BIT,
		.channel_mode = US_MR_CHMODE_NORMAL
	};

	// Initialize USART1
	usart_init_rs232(UART_PERIPHERAL, &usart_settings, sysclk_get_peripheral_hz());

	// Enable RX and TX
	usart_enable_tx(UART_PERIPHERAL);
	usart_enable_rx(UART_PERIPHERAL);

	// Configure LEDs as output
	pio_set_output(LED_PIO, LED_PIN_MASK, LOW, DISABLE, ENABLE);
	pio_set_output(LEDB_PIO, LEDB_PIN_MASK, LOW, DISABLE, ENABLE);
	pio_set_output(LEDC_PIO, LEDC_PIN_MASK, LOW, DISABLE, ENABLE);

	PIOC->PIO_OER |= (1<<17);     // Enable Output
	PIOC->PIO_PER |= (1<<17);     // Enable PIO control

	
	delay_ms(2000);
	while(Table==0){
		communicate();

	}
	
	//Go to the junction after table is selected
	if(Temp==0){
		table_acceleration();
		if(Table==1){
			leftTurn1();
			Temp=1;
			
		}
		else if (Table==2) {
			PIOC->PIO_CODR=(1<<17);
			rightTurn1();
			Temp=1;
		}
		
	}
	
	
	//wait for the customer input to confirm that the food was taken
	if(Temp==1){ 
		Return=0;
		delay_ms(1000);
		while(Return==0){
			
			communicate();
			
		}
		
		Temp=2;
		
		//If the selected table is 1 turn left
		if(Table==1 && Temp == 2 && Return == 1){
			leftTurn2();
			Temp = 3;
		}
		
		//If the selected Table is 2 turn right
		if (Table==2 && Temp == 2 && Return == 1){
			rightTurn2();
			// left motor
			PIOC->PIO_OER |= (1<<7);     // Enable Output
			PIOC->PIO_PER |= (1<<7);     // Enable PIO control
			PIOC->PIO_SODR = (1<<7);

			// right motor
			PIOC->PIO_OER |= (1<<6);     // Enable Output
			PIOC->PIO_PER |= (1<<6);     // Enable PIO control
			PIOC->PIO_CODR = (1<<6);
			Temp = 3;
		}
		
		
		
		Done=0;
		junction_count=0;
		
		//return to the destination
		table_acceleration_return();
		Temp=4;
		PIOC->PIO_CODR=(1<<17);
	}
	
}
 
 /// Reaching the junction where the table exists ///
void table_acceleration(void){
	temp=0;
	temp_2=0;

	//acceleration S curve
	for (float t = 3.0f; t <= 8.0f; t += 0.1f) {
		 Velocity = calculate_s_curve_velocity_acceleration(t);
		 frequency = 40 * Velocity;
		 processLineFollowing();
		 delay_ms(25);
		 
        //check for any junction
		if (((readLeftSensor() == 1) && (readRightSensor() == 1)) && (Done==0)){
			junction_count=junction_count+1;
			if(junction_count==2){
				decelerationScurve(calculate_time_from_velocity_deceleration(Velocity));
				Done=1;
			}
			 
			delay_ms(2000);
		}
		 
	 }

	//Function to reach the table once the Scurve accceleration is done
	table_acceleration_2();
}

void table_acceleration_2(void){

	//Going from the constant speed reached at the end of Scurve
	while ((temp==0) && (Done == 0) &&  ((readLeftSensor() == 0) && (readRightSensor() == 0))) {
		frequency = 40 * Velocity;
		processLineFollowing();
		
		//check for any obstacle
		if ((obstacle_flag) && (Done==0)){
			decelerationScurve(calculate_time_from_velocity_deceleration(Velocity));
			 
			while(temp_2==0){
				for (int i = 0; i <= 56000000; i++) {
					if(i==56000000){
						if(!(obstacle_flag)){
							temp_2=1;
						}
						 
					}
				}
			}
			temp=1;
		}

		//check for the junction and increment the variable when found
		if (((readLeftSensor() == 1) || (readRightSensor() == 1)) && (Done==0)){
			junction_count=junction_count+1;
			if(junction_count==2){
				 
				decelerationScurve(calculate_time_from_velocity_deceleration(Velocity));
				temp=1;
				Done=1;
			}
			 
			delay_ms(3000);
			 
			 
		 }
	 }
	 if(Done==0){
		 table_acceleration();
	 }
}
 
///Returning to the starting point ///
void table_acceleration_return(void){
	temp=0;
	temp_2=0;

	//Acceleration Scurve	
	for (float t = 3.0f; t <= 8.0f; t += 0.1f) {
		Velocity = calculate_s_curve_velocity_acceleration(t);
		frequency = 40 * Velocity;
		processLineFollowing(); 
		delay_ms(25);
		 
		// check for any junction
		if (((readLeftSensor() == 1) && (readRightSensor() == 1)) && (Done==0)){
			junction_count=junction_count+1;
			if(junction_count==3){
				decelerationScurve(calculate_time_from_velocity_deceleration(Velocity));
				Done=1;
			}
			 
			delay_ms(2000);
		 }
		 
	 }
	 table_acceleration_return_2();
}
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

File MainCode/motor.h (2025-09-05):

#include <stdint.h>
#include "sam3xa.h"         
#include <asf.h>
#include <math.h>
#include <stdint.h>
#include <stdbool.h>



#define  LEFT_MOTOR_DIR 7				//PC7 (5)
#define  LEFT_MOTOR_PU 5				//PC5 (34)
#define  LEFT_MOTOR_PWM_CHANNEL 1

//right motor
#define  RIGHT_MOTOR_DIR 6				//PC6 (3)
#define  RIGHT_MOTOR_PU 3				//PC3 (36)
#define  RIGHT_MOTOR_PWM_CHANNEL 0

//motors
float leftMotorSpeed;
float rightMotorSpeed;
uint32_t frequency=40*75;

//left motor
uint32_t desiredFrequencyLeft = 75;

//right motor
uint32_t desiredFrequencyRight = 75;


void enablePWMPeripheral(void);

//Enable/Disable Peripherals
void leftMotorPIOEnable(void);
void rightMotorPIOEnable(void);

//line following
void setup_pwm(void);
void mdrive(uint32_t desired_left, uint32_t desired_right);

void leftMotorPIOEnable(void){
	PIOC->PIO_PER |= (1 << LEFT_MOTOR_DIR); // Enable PIO control
	PIOC->PIO_OER |= (1 << LEFT_MOTOR_DIR); // Enable as output
}

void rightMotorPIOEnable(void){
	PIOC->PIO_PER |= (1 << RIGHT_MOTOR_DIR); // Enable PIO control
	PIOC->PIO_OER |= (1 << RIGHT_MOTOR_DIR); // Enable as output
}

void enablePWMPeripheral(void) {
	
	// Enable PWM peripheral clock using PMC (Power Management Controller)
	PMC->PMC_PCER1 = (1 << (36 - 32)); // Enabling PWM peripheral
	
	PIOC->PIO_PDR = (1 << LEFT_MOTOR_PU); // Disable PIO control for PC2
	PIOC->PIO_ABSR |= (1 << LEFT_MOTOR_PU); // Select peripheral B for PC2 (PWM)
	
	
	PIOC->PIO_PDR = (1 << RIGHT_MOTOR_PU); // Disable PIO control for PC4
	PIOC->PIO_ABSR |= (1 << RIGHT_MOTOR_PU); // Select peripheral B for PC4 (PWM)
	
	// Configure PWM clock
	PWM->PWM_CLK = PWM_CLK_PREA(0) | PWM_CLK_DIVA(84); // 84MHz / 84 = 1MHz  //base freq
	
	// Configure PWM Channel 0 LEFT MOTOR
	PWM->PWM_CH_NUM[0].PWM_CMR = PWM_CMR_CPRE_CLKA; // Use Clock A
	
	// Configure PWM Channel 1 RIGHT MOTOR
	PWM->PWM_CH_NUM[1].PWM_CMR = PWM_CMR_CPRE_CLKA; // Use Clock A
}

void mdrive(uint32_t desired_left, uint32_t desired_right) {
	
	// Calculate period ticks for 1MHz clock
	uint32_t periodTicks_left = 1000000 / desired_left;
	uint32_t periodTicks_right = 1000000 / desired_right;
	
	
	PWM->PWM_CH_NUM[1].PWM_CPRD = periodTicks_left;     // we divide the base freq by this to determine the PWM freq
	PWM->PWM_CH_NUM[1].PWM_CDTY = periodTicks_left / 2; // Set duty cycle to 50% for LEFT motor
	
	
	PWM->PWM_CH_NUM[0].PWM_CPRD = periodTicks_right; // Set period for RIGHT motor (Channel 1)
	PWM->PWM_CH_NUM[0].PWM_CDTY = periodTicks_right / 2; // Set duty cycle to 50% for RIGHT motor
	
	if(desired_left==0 && desired_right==0){
		PWM->PWM_DIS = (1 << 0); // disable Channel 0
		PWM ->PWM_DIS = (1 << 1); // disable Channel 1

	}
	else if (desired_left==0 ){
		PWM->PWM_DIS = (1 << 1);  // disable Channel 1
		PWM->PWM_ENA = (1 << 0);  // Enable Channel 0
	}
	else if (desired_right==0){
		PWM->PWM_ENA = (1 << 1); // Enable Channel 1
		PWM ->PWM_DIS = (1 << 0);// disable Channel 0
	}
	else{
		PWM->PWM_ENA = (1 << 0); // Enable Channel 0
		PWM->PWM_ENA = (1 << 1); // Enable Channel 1
	}
}

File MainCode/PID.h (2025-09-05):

#include <stdint.h>
#include "sam3xa.h"
#include <asf.h>
#include <math.h>
#include "sam3xa.h"
#include <stdint.h>
#include <stdbool.h>

// PID constants
int PID(int current_error);
int update_pid(void);
void processLineFollowing(void);
int update_pid_decelaration(void);
float error;

//Line Following Constants
float Kp = 25; 
float Ki = 0.0;
float Kd = 0;
int last_error = 0;
int integral = 0;

int PID(int current_error)
{
	integral += current_error;
	int derivative = current_error - last_error;
	int output = (Kp_d * current_error) + (Ki * integral) + (Kd * derivative);
	last_error = current_error;
	return output;
}


int update_pid(void){
	// Read sensor values 
	uint8_t sensors[4];
	sensors[0] = (PIOD->PIO_PDSR & (1 << 6)) != 0;
	sensors[1] = (PIOD->PIO_PDSR & (1 << 5)) != 0;
	sensors[2] = (PIOD->PIO_PDSR & (1 << 2)) != 0;
	sensors[3] = (PIOD->PIO_PDSR & (1 << 1)) != 0;
	

	// Weights 
	int8_t weights[4] = {-3, -1, 1, 3};

	// Error calculation 
	int16_t sum = 0;
	uint8_t active_count = 0; //# of sensors that are high

	for (int i = 0; i < 4; i++) {
		if (sensors[i]) {
			sum += weights[i];
			active_count++;
		}
	}

	int16_t Error = 0;
	if (active_count > 0) {
		Error = sum / active_count;
	}
	int output = PID(Error);
	return output;
}

//LineFollowing for the deceleration curve
void processLineFollowing_deceleration(void) {
	error = update_pid_decelaration();
	float error_mini = (error * 0.2);
	if (frequency < 600) {
		leftMotorSpeed = 0;
		rightMotorSpeed = 0;
	}
	
	else {
		leftMotorSpeed = frequency - (40 * error_mini);
		rightMotorSpeed = frequency + (40 * error_mini);
	}
	mdrive(leftMotorSpeed, rightMotorSpeed);
	delay_ms(20);
}

int update_pid_decelaration(void) {
	// Read sensor values 
	uint8_t sensors[4];
	sensors[0] = (PIOD->PIO_PDSR & (1 << 6)) != 0;
	sensors[1] = (PIOD->PIO_PDSR & (1 << 5)) != 0;
	sensors[2] = (PIOD->PIO_PDSR & (1 << 2)) != 0;
	sensors[3] = (PIOD->PIO_PDSR & (1 << 1)) != 0;
	
	int8_t weights[4] = {-3,-1, 1, 3};
	int16_t sum = 0;
	uint8_t active_count = 0;
	
	for (int i = 0; i < 4; i++) {
		if (sensors[i]) {
			sum += weights[i];
			active_count++;
		}
	}
	
	int16_t Error = 0;
	if (active_count > 0) {
		Error = sum / active_count;
	}
	int output = PID(Error);
	return output;
}

//For following the metal Line
void processLineFollowing(void){
	error=update_pid();
	float error_mini=(error*0.2);

	leftMotorSpeed=frequency-(40*error_mini);
	rightMotorSpeed=frequency+(40*error_mini);
	
	mdrive(leftMotorSpeed,rightMotorSpeed);
	delay_ms(20);
}
